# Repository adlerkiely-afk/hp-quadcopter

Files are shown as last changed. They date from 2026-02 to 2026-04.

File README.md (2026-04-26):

# hp-quadcopter 

Ground up engineering project designing and building a high peformance quadcopter. Every component of airframe is designed from scratch in Fusion360 and fabricated in a p2s 3d printer, final iteration will be a carbon fiber filled pla filament. The project is structured in two iterations - this repository documents Iteration 1 (6S) which establishes a peformance baseline. Targeting 160-175 km/h, with Iteration 2 (8S) targeting 200+ km/h.

## Project Goals 
-Design a custom airframe rocket-geometry in Fusion360
-Run CFD analysis on the fuselage geometry using SimScale to quantify drag reduction vs a standard plate center stack
-Engineer and document component selections with rationale
-Achieve a GPS measured top speed exceeding 140 km/h on 6S 
-Document full process to professional standard.

## Specs - Iteration 1 
-**Frame**: Custom Design, carbon fiber filled filament 
-**Motors**: AOS Supernova 2207 1980 KV x4
-**Power System**: 6S LiPo, 1000-1300mAh
-**Flight Controller**: SpeedyBee F7 V3
-**Target Speed**: 160-175 km/h calm air 

## Tools Used
-**Fusion 360**: Airframe CAD Design
-**SimScale**: CFD analysis for drag reduction
-**MATLAB**: Flight data analysis and plotting
-**Bambu Lab P2S**: Fabrication 

## Repository Structure
- '/docs' - Document requirements, test procedures, test reports
- '/cad' - Fusion 360 design files
- '/analysis' - Flight data analysis scripts
- '/cfd' - SimScale results, tests

## Project Status 
Phase 2 - Print and Test Frame

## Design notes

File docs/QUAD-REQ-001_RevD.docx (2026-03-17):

HIGH PERFORMANCE QUADCOPTER

System Requirements Document

Rocket Geometry Airframe | 6S Build | Iteration 1 of 2

Document ID | QUAD-REQ-001 | Revision | D
Author | Adler Kiely | Date | 3/16/2026

# 1. Purpose

This document defines the system-level requirements for Iteration 1 of the High Performance Quadcopter project. This iteration uses a 6S power system with the AOS Supernova 2207 1980KV motor to validate the custom airframe design, establish a performance baseline, and inform the design decisions for Iteration 2 which targets 200+ km/h on an 8S power system.

All design decisions made throughout the project shall be traceable to the requirements defined here. This project develops practical aerospace engineering skills including aerodynamic shaping, structural design, propulsion sizing, CFD analysis, and flight test data analysis.

# 2. Mission Overview

## 2.1 Mission Statement

Design, fabricate, and flight-test a high performance quadcopter featuring a custom streamlined rocket-geometry fuselage, fabricated from carbon fiber filled filament, powered by a 6S electrical system with AOS Supernova 2207 1980KV motors and 5-inch propellers. Target top speed is 160-175 km/h in calm air, with 185-200 km/h achievable downwind.

## 2.2 Iteration Strategy

This project is structured as two deliberate engineering iterations:

- Iteration 1 (this document): 6S power system — validate airframe, establish performance baseline, document lessons learned
- Iteration 2 (future): 8S power system with AOS Supernova 1570KV — target 200+ km/h in calm air based on Iteration 1 data

This two-iteration approach is intentional engineering practice. Iteration 1 data directly informs Iteration 2 design decisions. Both iterations together form a stronger portfolio narrative than a single build.

## 2.3 Concept of Operations

The vehicle operates outdoors in open areas under direct pilot RC control with visual line of sight maintained at all times. Flight operations progress through structured phases:

- Phase 1: Hover and stability validation — verify airframe integrity and establish PID baseline
- Phase 2: Progressive speed buildup — incremental speed runs with data logging at each stage
- Phase 3: Maximum speed runs — GPS-logged runs in calm air and downwind to measure top speed
- Phase 4: Characterization — document flight time, handling, and full performance envelope

# 3. Performance Requirements

Note: Speed targets are for Iteration 1 (6S). Iteration 2 (8S) will target 200+ km/h in calm air.

ID | Requirement | Priority
PR-01 | Vehicle shall achieve a minimum top speed of 140 km/h in calm air conditions | High
PR-02 | Vehicle shall achieve a target top speed of 160-175 km/h in calm air conditions | High
PR-03 | Vehicle shall achieve 185-200 km/h ground speed in favorable downwind conditions (20-30 km/h tailwind) | Medium
PR-04 | Vehicle thrust-to-weight ratio shall exceed 10:1 at full throttle on 6S | High
PR-05 | Vehicle shall achieve a minimum flight time of 3 minutes at full throttle | High
PR-06 | Vehicle shall achieve a minimum flight time of 5 minutes at 60% throttle cruise | Medium
PR-07 | Vehicle shall maintain stable controlled flight at speeds up to 120 km/h minimum | High
PR-08 | Vehicle shall achieve stable hover without pilot correction for a minimum of 5 seconds | High
PR-09 | Theoretical top speed shall be calculated from motor KV, voltage, and prop pitch before first flight and compared to GPS measured speed in test report | High

# 4. Airframe & Structural Requirements

ID | Requirement | Priority
AF-01 | Frame shall be designed entirely from scratch in Fusion 360 — no templates or downloaded STL files permitted | High
AF-02 | Frame shall be fabricated from carbon fiber filled filament (PA-CF, PLA-CF, or equivalent) | High
AF-03 | Center body shall incorporate a streamlined fuselage geometry to reduce frontal drag versus a standard flat plate center stack | High
AF-04 | Fuselage geometry shall be designed to minimize frontal drag — aerodynamic shaping rationale shall be documented in the project report | High
AF-05 | Frame arms shall be designed with wall thickness and geometry calculated for aerodynamic and motor torque loads at maximum speed | High
AF-06 | All printed parts shall be oriented during slicing to align layer lines with primary load direction | High
AF-07 | Vehicle center of gravity shall be within 5mm of geometric center in X and Y axes | High
AF-08 | Frame shall be compatible with motor mounting pattern physically verified as 12x12mm (M3 mounting) — supersedes original 16x16mm / 19x19mm entry | High
AF-09 | Arms shall be designed as replaceable components to allow crash repair without reprinting the full frame | Medium
AF-10 | Frame mass budget shall be estimated at design phase — weight of each printed component recorded before printing | Medium

# 5. Propulsion System Requirements

ID | Requirement | Priority
PS-01 | Motors shall be AOS Supernova 2207 1980KV — rated for 5-6S operation | High
PS-02 | ESCs shall be rated for a minimum of 35A continuous current on 6S (25.2V) | High
PS-03 | Propellers shall be HQ 5x4.5x3 V1S — the reference tested prop for this motor | High
PS-04 | Battery shall be 6S LiPo, 1000-1300mAh capacity, minimum 100C discharge rating | High
PS-05 | Motor selection shall be justified by documented thrust analysis showing predicted thrust at full throttle on 6S | High
PS-06 | Propeller selection shall be justified by pitch speed calculation showing theoretical maximum speed | High
PS-07 | Total system weight including battery shall be calculated at design phase to verify thrust-to-weight requirement PR-04 | High
PS-08 | Design reference thrust value shall be 1,980g per motor at full throttle on 6S per published test data | High

# 6. Electronics Requirements

ID | Requirement | Priority
EL-01 | Flight controller shall be SpeedyBee F7 V3 or equivalent — F7 processor required for high speed control loop demands | High
EL-02 | RC receiver shall be Radiomaster RP4TD (ELRS 2.4GHz true diversity) paired with Radiomaster Boxer ELRS transmitter — configured with failsafe | High
EL-03 | All electronics shall be mounted with vibration isolation to protect IMU accuracy at high speed | High
EL-04 | Flight controller shall log IMU data, motor outputs, and GPS speed to onboard blackbox every flight | High
EL-05 | Wiring shall be routed and secured inside or flush with fuselage to minimize aerodynamic interference | Medium
EL-06 | FPV camera shall be Caddx Ratel 2 (analog) — powered from VTX 5V BEC rail; video signal routed to VTX video-in pad | High
EL-07 | Video transmitter shall be Rush Tank Mini 5.8GHz — SmartAudio control via FC UART; antenna exiting fuselage through dedicated slot | High
EL-08 | GPS module shall be HGLRC M100 Mini (u-blox M10) — configured at 10Hz; GPS speed field enabled in blackbox to satisfy PR-09 | High

# 7. Documentation Requirements

ID | Requirement | Priority
DOC-01 | All design decisions shall be documented with engineering rationale at time of decision — not reconstructed after the fact | High
DOC-02 | Theoretical top speed calculation shall be committed to GitHub before first flight | High
DOC-03 | Thrust-to-weight calculation using actual component weights shall be committed to GitHub before first flight | High
DOC-04 | Formal test procedures shall be written prior to executing any test | High
DOC-05 | All flight test sessions shall produce a written test report comparing actual results to predictions | High
DOC-06 | All files shall be committed to GitHub throughout the project with descriptive commit messages — not uploaded at completion | High
DOC-07 | An Iteration 1 lessons learned report shall be produced at completion to formally inform Iteration 2 design | High
DOC-08 | Final project report shall be produced in LaTeX and published to the repository | Medium

# 8. Budget — Iteration 1 (6S)

Component | Est. Cost | Actual Cost | Notes
AOS Supernova 2207 1980KV Motors x4 | $60–$80 | | Best 6S thrust in class
T-HOBBY F55A PRO III 4-in-1 ESC (30x30) | $50–$70 | $45.00 | 55A cont., BLHeli32, 3–8S
SpeedyBee F7 V3 Flight Controller | $40–$55 | $30.00 | F7 processor, 6S compatible
HQ 5x4.5x3 V1S Propellers + spares | $15–$20 | $15–$20 | Reference prop for this motor
Gaoneng GNB HV 6S 1300mAh 160C (XT60) | $45–$60 | $90.00 | HV LiPo, 198g
Radiomaster RP4TD ELRS Receiver | $18–$25 | $17.00 | True diversity, dual SX1281
HGLRC M100 Mini GPS (u-blox M10) | $18–$25 | $40.00 | 10Hz, blackbox speed log
Caddx Ratel 2 FPV Camera | $25–$35 | $55.00 | 1/1.8" starlight, 5–40V
Rush Tank Mini VTX 5.8GHz | $25–$35 | | 25–800mW, SmartAudio
Nichicon ES/UHE 1000µF 35V Capacitor | $2–$4 | $3.00 | 35V rated — correct for 6S HV
6S Balance Charger | $25–$40 | | ISDT Q6 Plus recommended
Carbon fiber filled filament 1kg | $30–$50 | | PA-CF — airframe
Miscellaneous (XT60, wiring, hardware) | $13–$20 | | Connectors, M3 hardware, heatshrink
Iteration 1 Total | $366–$519 | $415.50 (partial) | Iter. 2 adds ~$80-120

# 9. Success Criteria — Iteration 1

Iteration 1 is considered successfully complete when all of the following are demonstrated:

- Vehicle achieves stable controlled hover for a minimum of 30 seconds
- Vehicle achieves a GPS-measured top speed of 170 km/h
- Theoretical top speed calculation produced and compared to measured result in test report
- Thrust-to-weight ratio verified to exceed 10:1 by calculation using actual component weights
- All High priority requirements verified through formal test procedures
- Lessons learned report produced to formally inform Iteration 2 design
- Complete documentation published to GitHub with timestamped commit history
- Frame is an original Fusion 360 design — not a template or downloaded file

# 10. Revision History

Rev | Date | Description
A | 2/16/2026 | Initial release — 4S 5 inch configuration
B | 2/17/2026 | Revised to 6S high performance, added rocket geometry fuselage requirements
C | 2/19/2026 | Revised to 6S 5 inch — Iteration 1 of 2. Iteration 2 targets 8S 200+ km/h. Added SimScale CFD requirement.

D

3/16/2026

AF-08 corrected: motor mount physically verified as 12x12mm. AF-04 revised: SimScale/CFD requirement removed, replaced with geometry documentation requirement. EL-02 updated to name Radiomaster RP4TD specifically. EL-06/07/08 added: FPV camera, VTX, and GPS promoted from stretch goals to core requirements. DOC IDs corrected to hyphenated format. Stretch goals section removed entirely. Section 8 budget updated with confirmed components and partial actuals. Section 9 success criteria revised: target speed set to 170 km/h, flight time criterion removed, SimScale criterion removed, hover duration retained at 30 seconds.

Adler Kiely — Rocket Geometry Airframe Build Page

QUAD-REQ-001 | Rev D | HIGH PERFORMANCE QUADCOPTER — System Requirements

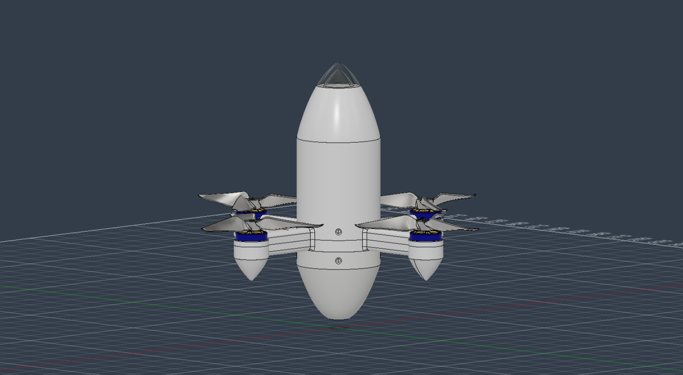
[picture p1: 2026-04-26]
docs/images/quadCADpng001.png

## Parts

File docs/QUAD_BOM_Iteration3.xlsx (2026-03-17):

HIGH PERFORMANCE QUADCOPTER — COMPONENT BILL OF MATERIALS
QUAD-REQ-001 Rev C · Iteration 1 · 6S Build · Airframe excluded · 17 Mar 2026
# | Category | Component | Part / Specification | Req. ID | Qty | Est. Cost (USD) | Status
1 | Power | LiPo Battery | Gaoneng GNB HV 6S 22.8V 1300mAh 160C · XT60 · 198g | PS-04 | 1 | $40 | Confirmed
2 | Propulsion | Brushless Motor ×4 | AOS Supernova 2207 1980KV · 12×12mm mount · 1980g thrust ea. | PS-01 | 4 | $90 | Confirmed
3 | Propulsion | Propellers | HQ 5×4.5×3 V1S polycarbonate · 3.75g ea. · CW+CCW pack + spares | PS-03 | 1 | $15–$20 | Confirmed
4 | Electronics | 4-in-1 ESC | T-HOBBY F55A PRO III · 3–8S · 55A cont. · BLHeli32 · 30×30 | PS-02 | 1 | $118.00 | Confirmed
5 | Electronics | Flight Controller | SpeedyBee F7 V3 · STM32F7 · ICM-42688P IMU · 30×30 | EL-01 | 1 | $45.00 | Confirmed
6 | RC Link | RX — Receiver | Radiomaster RP4TD · ELRS 2.4GHz · true diversity · dual SX1281 · 1.4g | EL-02 | 1 | $30 | Confirmed
7 | RC Link | RX antennas | Stock 65mm 2.4GHz T-antennas ×2 · bundled with RP4TD · U.FL | EL-02 | 1 | $0 | Bundled — $0
8 | Sensors | GPS Module | HGLRC M100 Mini · u-blox M10 · 10Hz · blackbox speed log | PR-09/SG-02 | 1 | $17 | Confirmed
9 | FPV | FPV Camera | Caddx Ratel 2 · 1/1.8" starlight · 1200TVL · 165° FOV · 5–40V · 5.9g | SG-01 | 1 | $40 | Confirmed
10 | FPV | Video Transmitter | Rush Tank Mini · 5.8GHz · 25–800mW · SmartAudio · 7–36V · 20×20 · 5.4g | SG-01 | 1 | $55 | Confirmed
11 | FPV | VTX antenna | Stock MMCX 5.8GHz omni · bundled with Rush Tank Mini | SG-01 | 1 | $0 | Bundled — $0
12 | Electronics | Bulk Capacitor | Nichicon ES/UHE 1000µF 35V radial · correct voltage margin for 6S HV | EL-03 | 1 | $3 | Confirmed
13 | Consumables | Wiring & Connectors | XT60 pigtail · ESC leads · silicone wire | — | 1 | $8–$12 | Estimate
14 | Consumables | Hardware | M3 bolts · standoffs · heat shrink · zip ties | — | 1 | $5–$8 | Estimate
15 | Power | Balance Charger | ISDT Q6 Plus or equivalent · 6S capable | — | 1 | $25–$40 | Recommended
ESTIMATED TOTAL (excl. airframe) |  |  |  |  |  | ~$400 | Charger est. separately

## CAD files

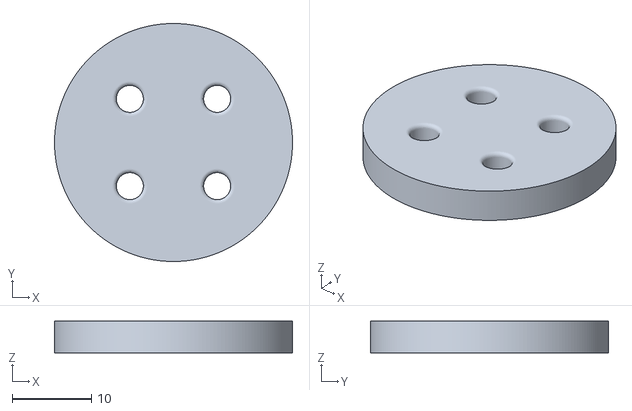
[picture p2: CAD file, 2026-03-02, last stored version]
cad/stl/motorMountPrintV2.stl
30.0 x 30.0 x 4.00

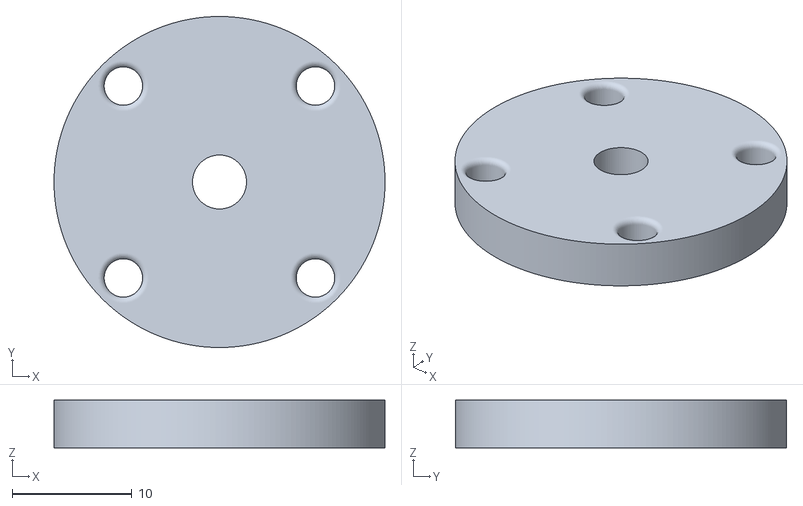
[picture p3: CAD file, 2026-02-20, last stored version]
cad/stl/motor-retention-plate-v1.stl
27.6 x 27.6 x 4.00

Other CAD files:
cad/Highpower-Quadcopter.f3d

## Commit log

2026-02-20 motor-retention-plate STL
    [motor-retention-plate-v1.stl]
2026-02-20 quadcopter-project f360 file
    [Highpower-Quadcopter.f3d]
2026-02-20 Create motor-retention-plate
2026-02-20 Add motor retention plate v1- rationale, dimensions, print settings
2026-03-02 Added v2 motor retention plate
    Fixed mounting pattern, diameter, removed center hole
2026-03-17 component costs
    [QUAD_BOM_Iteration3.xlsx]
2026-04-26 cadPng of iteration 1 first test print
